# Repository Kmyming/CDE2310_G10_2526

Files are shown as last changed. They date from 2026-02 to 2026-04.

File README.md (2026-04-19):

# Fundamentals of System Design – CDE2310

> A ROS2-based autonomous mission stack using LiDAR, RPi Camera & Rack-and-Pinion Spring-Loaded Launcher for a warehouse maze environment deployment.

## 📘 Project Overview

Welcome to the official repository for our CDE2310 System Design project — a fully autonomous robot capable of:

- 🌐 Frontier exploration, real-time mapping, & FSM Orchestration
- 📷 Detecting static and dynamic delivery zones via ArUco Markers
- 🚀 Dock at delivery zones to launch ping pong ball payloads into delivery receptacles

---
## 📄 Documentation Map

- [Requirements Specification](docs/requirements-specification.md)
- [Concept of Operations](docs/con-ops.md)
- [High Level Design](docs/high-level-design.md)
- [Software Subsystem: Navigation and FSM](docs/subsystem-nav-fsm.md)
- [Software Subsystem: ArUco Marker Detection](docs/subsystem-software-aruco.md)
- [Mechanical Subsystem](docs/subsystem-mechanical.md)
- [Electrical Subsystem](docs/subsystem-electrical.md)
- [Interface Control Document](docs/interface-control-document.md)
- [Software and Firmware Development](docs/software-firmware-development.md)
- [Testing Documentation](docs/testing-documentation.md)
- [User Manual](docs/user-manual.md)
- [Areas for Improvement](docs/improvements.md)
- [Appendix](docs/appendix.md)

👉 **Visit our GitHub Pages site here**:  
🔗 [https://kmyming.github.io/CDE2310_G10_2526/](https://kmyming.github.io/CDE2310_G10_2526/)

## 📂 Project Structure

This repository includes:

- `/docs`: Website content served via GitHub Pages
- `/src`: ROS2 packages and simulation files
- CAD models and system schematics
- Launch and config files for simulation and real-world deployment

---

## 🧥 Meet the Team

<div style="text-align: center;">
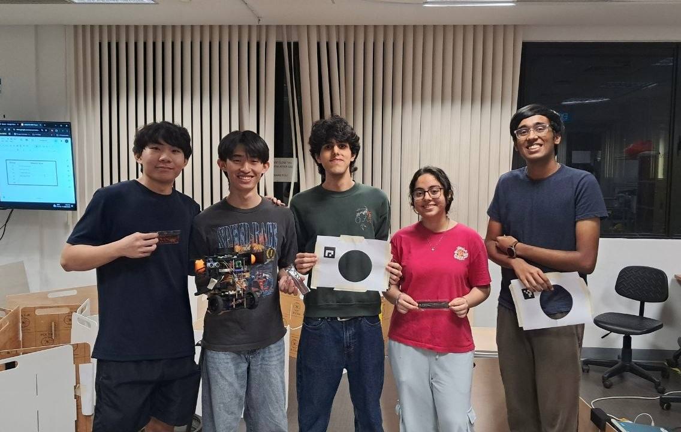
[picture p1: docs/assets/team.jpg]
team
  
</div>

---

## 🛠️ Tech Stack

- ROS2 Humble
- SLAM Toolbox
- Custom Open-source ROS2 Frontier-based exploration
- OpenCV ArUco marker detection
- Python / C++
- Custom 3D-printed parts + electronics integration

---

## Notes
- `CHANGELOG.md` is the repository release-history reference.

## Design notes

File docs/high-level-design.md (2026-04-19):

## 🔗 Navigation

- [Home](index.md)
- [Requirements Specification](requirements-specification.md)
- [Concept of Operations](con-ops.md)
- [High Level Design](high-level-design.md)
- [Software Subsystem: Navigation and FSM](subsystem-nav-fsm.md)
- [Software Subsystem: ArUco Marker Detection](subsystem-software-aruco.md)
- [Mechanical Subsystem](subsystem-mechanical.md)
- [Electrical Subsystem](subsystem-electrical.md)
- [Interface Control Document](interface-control-document.md)
- [Software and Firmware Development](software-firmware-development.md)
- [Testing Documentation](testing-documentation.md)
- [User Manual](user-manual.md)
- [Areas for Improvement](improvements.md)
- [Appendix](appendix.md)

---

# High Level Design

## System Overview

The system is a ROS 2 Humble-based autonomous mobile robot (AMR) built on a TurtleBot3 Burger platform. It is split across two compute nodes: a **remote laptop** running the mission orchestration, SLAM, and navigation stack, and an **on-board Raspberry Pi 4** handling camera processing, docking control, and hardware actuation.

The five core subsystems — Navigation & SLAM, Finite State Machine (FSM), ArUco Marker Detection, Docking Controller, and Shooter Controller — run as independent ROS 2 nodes and communicate exclusively through published topics. No direct function calls cross subsystem boundaries.

---

## Deployment Architecture

The system compute is split between two hosts. The laptop handles all heavy processing; the Pi handles all hardware-facing tasks.

### Remote Laptop (Ubuntu 22.04)

- SLAM Toolbox → Generates `/map` for navigation  
- exploration_controller → Frontier exploration, A* path planning, pure pursuit tracking  
- fsm_controller → Mission state management and velocity multiplexing  
- RViz → Visualisation of map, robot pose, and paths  

### On-board Raspberry Pi 4

- aruco_pose_streamer → ArUco marker detection and TF pose publishing  
- docking_controller → Marker-guided docking control  
- shooter_controller → Launcher actuation and ultrasonic sensing  
- Sensors → Camera and LiDAR inputs  

### Communication

- All nodes communicate using ROS 2 DDS over Wi-Fi  
- No direct function calls between subsystems  
- All data exchange occurs via ROS 2 topics  

---

| Layer | Host | Responsibilities |
|---|---|---|
| **Laptop** | Remote PC (Ubuntu 22.04) | SLAM Toolbox, `exploration_controller`, `fsm_controller`, RViz visualisation |
| **Robot** | Raspberry Pi 4 (on-board) | `aruco_pose_streamer`, `docking_controller`, `shooter_controller`, camera + LiDAR |
---

## Runtime Components

| Node | Host | Role |
|---|---|---|
| `exploration_controller` | Laptop | Frontier-based exploration, A\* path planning, pure-pursuit tracking |
| `fsm_controller` | Laptop | Top-level mission state machine and velocity multiplexer |
| `aruco_pose_streamer` | Pi | ArUco marker detection and TF pose broadcast |
| `docking_controller` | Pi | Multi-stage marker-guided docking state machine |
| `shooter_controller` | Pi | Rack-and-pinion ball delivery, ultrasonic sensing, GPIO actuation |
| SLAM Toolbox | Laptop | Real-time 2D occupancy grid construction and localisation |
| RViz | Laptop | Live map, robot pose, and path visualisation |

---

## ROS 2 Data Flow

The diagram below shows how sensor data flows through all nodes to the motors, and how status signals feed back to the FSM.

```mermaid
flowchart TD
    LIDAR["/scan<br>LiDAR"] --> SLAM
    LIDAR --> EXP
    LIDAR --> DOCK

    ODOM["/odom<br>Odometry"] --> SLAM
    ODOM --> EXP
    ODOM --> DOCK

    CAM["/camera/image_raw<br>Camera"] --> ARUCO

    SLAM["SLAM Toolbox"] -->|/map| EXP

    ARUCO["aruco_pose_streamer"] -->|/tf aruco_marker_id| DOCK
    ARUCO -->|/marker_detected| FSM

    EXP["exploration_controller"] -->|/cmd_vel_nav| FSM
    EXP -->|/map_explored| FSM

    FSM["fsm_controller"] -->|/states| DOCK
    FSM -->|/shoot_type| SHOOT
    FSM -->|/cmd_vel| MOTORS

    DOCK["docking_controller"] -->|/cmd_vel_docking| FSM
    DOCK -->|/dock_done| FSM

    SHOOT["shooter_controller"] -->|/shoot_done| FSM

    MOTORS["TurtleBot3 Motors"]
```

---

## Mission State Flow

```mermaid
flowchart TD
    START(["Mission start"]) --> EXPLORE

    EXPLORE["EXPLORE<br>Frontier navigation"] -->|marker detected<br>unvisited zone| DOCK

    DOCK["DOCK<br>ArUco approach"] -->|dock_done = True| LAUNCH
    DOCK -->|dock_done = False| EXPLORE

    LAUNCH["LAUNCH<br>Ball delivery"] -->|shoot_done = True<br>+ 15 s hold| BACKUP

    BACKUP["BACKUP<br>Reverse 2 s"] --> EXPLORE

    EXPLORE -->|map_explored = True<br>AND marker_count ≥ 2| END

    END(["END<br>Robot halts"])
```

---

## Subsystem Descriptions

### Navigation & SLAM

The `exploration_controller` node implements autonomous frontier-based exploration. On each planning cycle it:

1. Receives the occupancy grid from `/map` and inflates walls by `expansion_size` cells to create a costmap.
2. Identifies frontier cells — free cells (`0`) adjacent to unknown cells (`-1`) — using a breadth-first scan.
3. Groups contiguous frontier cells using DFS and selects the top 5 largest groups.
4. Scores each group by `frontier_size / path_distance` and selects the highest-scoring reachable group.
5. Plans an A\* path from the robot's current grid cell to the frontier centroid, then fits a B-spline for smooth traversal.
6. Tracks the path using a pure-pursuit controller with a configurable lookahead distance.
7. Layers local obstacle avoidance on top: LiDAR scan sectors detect obstacles within `robot_r` and override path-following with evasive velocity commands.

When no frontier groups remain, `/map_explored = True` is published and exploration halts.

### Finite State Machine (FSM)

The `fsm_controller` node is the mission arbiter. It maintains the top-level state and acts as a **velocity multiplexer**, forwarding the correct controller's `Twist` output to `/cmd_vel` depending on the active state.

**Velocity multiplexing:**

| FSM State | Source published to `/cmd_vel` |
|---|---|
| `EXPLORE` | `/cmd_vel_nav` (exploration controller) |
| `DOCK` | `/cmd_vel_docking` (docking controller) |
| `BACKUP` | Hard-coded reverse: `linear.x = -0.1 m/s` |
| `LAUNCH`, `END` | Zero velocity (`Twist()`) |

### ArUco Marker Detection

The `aruco_pose_streamer` node runs on the Pi and processes every camera frame:

1. Converts ROS 2 `Image` messages to OpenCV `BGR` frames via `cv_bridge`.
2. Detects ArUco markers using `DICT_4X4_250` and `DetectorParameters`.
3. Estimates 6-DOF pose using `cv2.aruco.estimatePoseSingleMarkers` with camera intrinsics from `/camera/camera_info` (fallback pinhole model if intrinsics are invalid).
4. Broadcasts each detected marker's pose as a TF transform (`aruco_marker_<id>`).
5. Publishes `/marker_detected = True` (deduplicated — only published on state change).

Zone identification: marker ID `0` → `static` zone, marker ID `1` → `dynamic` zone.

### Docking Controller

The `docking_controller` node executes a geometric perpendicular docking manoeuvre guided by the ArUco marker's `tvec` and `rvec`.

```mermaid
flowchart TD
    IDLE([IDLE]) -->|FSM signals DOCK<br>+ marker visible| SEARCH
    SEARCH["SEARCH<br>Rotate until tx ≈ 0"] --> APPROACH
    APPROACH["APPROACH_1<br>Drive until tz < 0.30 m"] --> TURN_SIDE
    TURN_SIDE["TURN_SIDE<br>Rotate by π/2 − θ"] --> DRIVE_SIDE
    DRIVE_SIDE["DRIVE_SIDE<br>Drive lateral distance"] --> TURN_FACE
    TURN_FACE["TURN_FACE_MARKER<br>Re-centre tx ≈ 0"] --> FINAL
    FINAL["FINAL_APPROACH<br>Drive until tz < 0.10 m"] --> DONE(["DONE<br>/dock_done = True"])

    APPROACH -->|obstacle detected| OBS
    TURN_SIDE -->|obstacle detected| OBS
    DRIVE_SIDE -->|obstacle detected| OBS
    TURN_FACE -->|obstacle detected| OBS

    OBS["OBSTACLE_AVOIDANCE<br>Evade obstacle"] --> SPEC
    SPEC["SPECIAL_SEARCH<br>360° rotation"] -->|marker found| SEARCH
    SPEC -->|no marker| ABORT

    APPROACH -->|timeout| ABORT
    FINAL -->|timeout| ABORT

    ABORT(["ABORT<br>/dock_done = False"]) --> IDLE
    DONE --> IDLE
```

Key geometric logic in `APPROACH_1` → `TURN_SIDE`:

- Computes angle `θ` between the marker normal and the camera→marker vector using the marker's rotation matrix.
- Plans a lateral step of distance `tz × sin(θ)` to reach the perpendicular line.
- Turns by `(π/2 − |θ|)` to face perpendicular, drives the lateral distance, then turns back to face the marker.

**Watchdog timers** (both trigger `ABORT`):
- Marker invisible for > **30 seconds** continuously.
- Any single docking state active for > **45 seconds**.

### Shooter Controller

The `shooter_controller` node manages ball delivery via two servos and one ultrasonic sensor connected to the Pi's GPIO through `pigpio`:

| Component | GPIO Pin | Function |
|---|---|---|
| Gate servo | Pin 12 | Opens/closes to release one ball |
| Rack servo | Pin 13 | Continuous rotation — pulls back the launcher rack |
| Ultrasonic trigger | Pin 23 | HC-SR04 trigger pulse |
| Ultrasonic echo | Pin 24 | HC-SR04 echo return |

```mermaid
flowchart TD
    START([/shoot_type received]) --> TYPE{shoot_type?}

    TYPE -->|static| S1["Shot 1"]
    S1 --> S2["Shot 2"]
    S2 --> S3["Shot 3"]
    S3 --> DONE

    TYPE -->|dynamic| POLL["Poll ultrasonic"]
    POLL -->|distance > threshold| POLL
    POLL -->|distance ≤ threshold| LOAD["Load pass"]
    LOAD --> POLL2["Poll again"]
    POLL2 -->|distance ≤ threshold| LAUNCH["Launch"]
    LAUNCH --> DONE

    DONE(["/shoot_done = True"])
```

Ultrasonic distance is computed as a **median of 5 samples**, filtering out readings outside `[0.02 m, 4.0 m]`. Speed of sound is corrected for ambient temperature (`331.3 + 0.606 × T °C` m/s).

---

## ROS 2 Topic Summary

| Topic | Type | Publisher | Subscriber(s) |
|---|---|---|---|
| `/scan` | `LaserScan` | LiDAR driver | `exploration_controller`, `docking_controller` |
| `/odom` | `Odometry` | TurtleBot3 bringup | `exploration_controller`, `docking_controller` |
| `/map` | `OccupancyGrid` | SLAM Toolbox | `exploration_controller` |
| `/camera/image_raw` | `Image` | Camera node | `aruco_pose_streamer` |
| `/camera/camera_info` | `CameraInfo` | Camera node | `aruco_pose_streamer` |
| `/tf` | `TFMessage` | `aruco_pose_streamer` | `docking_controller`, `fsm_controller` |
| `/marker_detected` | `Bool` | `aruco_pose_streamer` | `fsm_controller` |
| `/cmd_vel_nav` | `Twist` | `exploration_controller` | `fsm_controller` |
| `/cmd_vel_docking` | `Twist` | `docking_controller` | `fsm_controller` |
| `/cmd_vel` | `Twist` | `fsm_controller` | TurtleBot3 motor driver |
| `/states` | `String` | `fsm_controller` | `docking_controller` |
| `/dock_done` | `Bool` | `docking_controller` | `fsm_controller` |
| `/shoot_type` | `String` | `fsm_controller` | `shooter_controller` |
| `/shoot_done` | `Bool` | `shooter_controller` | `fsm_controller` |
| `/map_explored` | `Bool` | `exploration_controller` | `fsm_controller` |
| `/exploration_path` | `Path` | `exploration_controller` | RViz |

---

## Design Rationale

**Decoupled subsystems via topics** — each node publishes and subscribes to well-defined topics. This allows any subsystem to be swapped, tested in isolation, or replaced without modifying other nodes.

**Laptop/Pi compute split** — SLAM and A\* are CPU-intensive; keeping them on the laptop prevents the Pi from becoming a bottleneck during real-time marker detection and GPIO actuation.

**Velocity multiplexer in FSM** — rather than having multiple nodes write directly to `/cmd_vel`, the FSM acts as a single gatekeeper. This prevents conflicting velocity commands and makes the priority logic explicit and auditable.

**Watchdog timers in docking** — the 30-second marker-loss watchdog and 45-second per-state watchdog ensure the robot never stalls indefinitely in a partially completed docking attempt, always returning to a known safe state (`ABORT` → `IDLE`).

**Parameter-driven configuration** — all thresholds, speeds, pin assignments, and timing values are exposed as ROS 2 parameters loaded from `params.yaml` at launch. No magic numbers exist in business logic, making tuning and re-calibration straightforward.

**Simulation parity** — the `enable_hardware = False` flag on the shooter node and standard Gazebo-compatible topic names mean the full software stack can be validated in simulation before any hardware run.

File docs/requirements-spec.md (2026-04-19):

# 🔗 Navigation
- [Home](index.md)
- [Requirements Specification](requirements-specification.md)
- [Concept of Operations](con-ops.md)
- [High Level Design](high-level-design.md)
- [Software Subsystem: Navigation and FSM](subsystem-nav-fsm.md)
- [Software Subsystem: ArUco Marker Detection](subsystem-software-aruco.md)
- [Mechanical Subsystem](subsystem-mechanical.md)
- [Electrical Subsystem](subsystem-electrical.md)
- [Interface Control Document](interface-control-document.md)
- [Software and Firmware Development](software-firmware-development.md)
- [Testing Documentation](testing-documentation.md)
- [User Manual](user-manual.md)
- [Areas for Improvement](improvements.md)
- [Appendix](appendix.md)

---

# Requirements Specification

## Problem Statement

The system must autonomously explore an unknown indoor warehouse-style arena, detect ArUco fiducial markers identifying two delivery receptacles, dock precisely in front of each receptacle, and deliver exactly three ping-pong balls per receptacle — all without manual teleoperation after mission start. One receptacle is static; the other moves laterally at an unknown speed, requiring sensor-gated delivery timing. The complete mission must be executed within a **25-minute window** on a TurtleBot3 Burger platform running ROS 2 Humble.

---

## Stakeholder Needs

- Autonomous exploration of a fully unknown maze environment with no prior map.
- Reliable detection and 6-DOF pose estimation of ArUco markers under realistic lighting and partial occlusion.
- Deterministic mission state transitions that handle both success and failure paths without operator input.
- Correct, sequenced ball delivery into both a static and a moving receptacle.
- Clear operator setup and shutdown procedures requiring minimal technical expertise.
- A single-command launch that brings up the full mission stack for both simulation and real hardware.

---

## Functional Requirements

### Navigation and Mapping

**FR-01** — The system shall autonomously build a 2D occupancy grid of the arena using LiDAR-based SLAM without any prior map data.

**FR-02** — The system shall implement frontier-based exploration to discover and navigate to unexplored regions of the map systematically, scoring frontiers by a ratio of frontier size to A\* path distance.

**FR-03** — The system shall plan collision-free paths to frontier targets using the A\* algorithm on the inflated costmap and track those paths using a pure-pursuit controller.

**FR-04** — The system shall apply local obstacle avoidance using segmented LiDAR scan sectors, overriding path-following commands when obstacles are detected within `robot_r` of the robot body.

**FR-05** — The system shall publish a `/map_explored` signal (`Bool`, `True`) when no valid frontier groups remain in the occupancy grid.

### Marker Detection

**FR-06** — The system shall detect ArUco markers (dictionary `DICT_4X4_250`) from the Raspberry Pi camera feed and estimate their 6-DOF pose (translation vector `tvec`, rotation vector `rvec`) using OpenCV's `estimatePoseSingleMarkers`.

**FR-07** — The system shall broadcast each detected marker's pose as a TF transform (`aruco_marker_<id>`) and publish a `/marker_detected` (`Bool`) signal when at least one marker is visible.

**FR-08** — The system shall identify the delivery zone type from the marker ID: marker ID `0` corresponds to the static receptacle zone; marker ID `1` corresponds to the dynamic receptacle zone.

**FR-09** — The system shall use a fallback pinhole camera model when valid intrinsics are not available from `/camera/camera_info`, logging a warning and continuing detection.

**FR-10** — The system shall suppress duplicate zone-detection signals: once a zone has been marked as visited by the FSM, further detections of that zone's marker shall be ignored.

### Mission State Machine

**FR-11** — The system shall implement a finite state machine (FSM) with the following top-level states: `EXPLORE`, `DOCK`, `LAUNCH`, `BACKUP`, and `END`.

**FR-12** — The FSM shall transition from `EXPLORE` to `DOCK` upon receiving a `/marker_detected = True` signal for an unvisited zone while in the `EXPLORE` state.

**FR-13** — The FSM shall transition from `DOCK` to `LAUNCH` upon receiving `/dock_done = True`, and return to `EXPLORE` upon receiving `/dock_done = False`.

**FR-14** — The FSM shall transition from `LAUNCH` to `BACKUP` after the shooter signals `/shoot_done = True` and a minimum hold duration of 15 seconds has elapsed.

**FR-15** — The FSM shall transition from `BACKUP` to `EXPLORE` after the robot has reversed for 2 seconds, clearing the delivery zone.

**FR-16** — The FSM shall transition to `END` when the map is fully explored and both delivery zones have been visited (`marker_count >= 2`).

**FR-17** — The FSM shall arbitrate velocity commands from the navigation controller (`/cmd_vel_nav`) and the docking controller (`/cmd_vel_docking`), publishing the active controller's output to `/cmd_vel` based on the current state.

### Docking

**FR-18** — The docking controller shall implement a multi-stage docking state machine with the states: `IDLE`, `SEARCH`, `APPROACH_1`, `TURN_SIDE`, `DRIVE_SIDE`, `TURN_FACE_MARKER`, `FINAL_APPROACH`, `DONE`, `ABORT`, `OBSTACLE_AVOIDANCE`, and `SPECIAL_SEARCH`.

**FR-19** — The docking controller shall rotate the robot until the marker's lateral offset `tx` is within ±0.01 m before beginning the approach.

**FR-20** — The docking controller shall compute a geometric perpendicular approach manoeuvre using the marker's pose angle `θ` when `tz < 0.30 m`, including a lateral drive step and a realignment turn.

**FR-21** — The docking controller shall terminate the final approach and publish `/dock_done = True` when `tz < 0.10 m` or the front LiDAR average reads below `0.20 m`.

**FR-22** — The docking controller shall publish `/dock_done = False` and transition to `ABORT` if the marker is continuously invisible for 30 seconds during any active docking state, or if any single docking state remains active for more than 45 seconds.

**FR-23** — The docking controller shall transition to `OBSTACLE_AVOIDANCE` when a proximate obstacle is detected during any docking state (except `FINAL_APPROACH`, `SPECIAL_SEARCH`, `DONE`, `ABORT`, and `IDLE`), and subsequently perform a 360° rotation scan (`SPECIAL_SEARCH`) to re-acquire the marker.

### Payload Delivery

**FR-24** — The shooter controller shall deliver exactly three ping-pong balls per docking event, using a rack-and-pinion servo mechanism actuated via GPIO through `pigpio`.

**FR-25** — For the static receptacle (`shoot_type = static`), the shooter shall fire three shots with the following inter-shot delays: ~0.1 s between shots 1 and 2, and ~7.1 s between shots 2 and 3.

**FR-26** — For the dynamic receptacle (`shoot_type = dynamic`), the shooter shall poll an ultrasonic sensor (HC-SR04 or equivalent) at regular intervals and only trigger each shot when the measured distance to the moving receptacle is ≤ 0.70 m, using a two-pass load-then-launch sequence.

**FR-27** — The shooter shall use a median of multiple ultrasonic samples per measurement to reduce noise, filtering out readings outside the valid range of `0.02 m` to `4.0 m`.

**FR-28** — The shooter controller shall publish `/shoot_done = True` upon successful completion of the full delivery sequence and `/shoot_done = False` on any exception during hardware actuation.

**FR-29** — The shooter controller shall support an `enable_hardware = False` simulation mode that completes the delivery sequence after a configurable delay without actuating any GPIO pins.

---

## Non-Functional Requirements

**NFR-01** — The entire mission stack shall be launchable with a single top-level `ros2 launch` command for both the simulation and real-hardware configurations.

**NFR-02** — The system shall expose stable, documented ROS 2 topic contracts (topic names, message types, QoS profiles) so that each subsystem can be developed, tested, and replaced independently.

**NFR-03** — All tunable parameters (speeds, thresholds, timeouts, pin assignments, servo pulse widths) shall be exposed as ROS 2 parameters configurable at launch time via a `params.yaml` file, with no hardcoded values in business logic.

**NFR-04** — The documentation shall be written in Markdown and remain compatible with GitHub Pages rendering.

**NFR-05** — The system shall log all state transitions and key sensor readings to `/rosout` at the `INFO` level to support post-run debugging.

---

## Constraints

**CON-01** — The robot platform is a TurtleBot3 Burger. No modifications to the core drive train or LiDAR mounting are permitted.

**CON-02** — The software stack shall target ROS 2 Humble on Ubuntu 22.04.

**CON-03** — Line-following techniques are prohibited. Navigation must be SLAM and sensor-based.

**CON-04** — The robot shall operate fully autonomously from the moment the mission clock starts. No teleoperation is permitted during the mission.

**CON-05** — The mission must be completed within 25 minutes.

**CON-06** — No more than six ArUco landmark markers may be used across the entire arena.

**CON-07** — The LiDAR's 360° field of view must not be obstructed by any mechanical or storage component mounted on the robot.

**CON-08** — The compute responsibilities are split: the Raspberry Pi 4 (on-board) handles camera processing, docking, and hardware actuation; the remote laptop handles SLAM, navigation, and the FSM.

---

## Performance Requirements

**PR-01** — The robot shall align with delivery receptacles with a lateral positional error of no more than ±10 cm at the point of delivery.

**PR-02** — The ball dispensing success rate (ball lands and remains inside the receptacle) shall be at least 70% per shot under normal operating conditions.

**PR-03** — The exploration algorithm shall cover at least 80% of the accessible arena area before declaring the map fully explored.

**PR-04** — The ArUco marker detection pipeline shall process camera frames in real time (≥10 Hz) and publish pose data with a latency of no more than 200 ms from frame capture.

**PR-05** — The docking controller shall complete a full docking sequence (from `SEARCH` to `DONE`) within 45 seconds per docking attempt under normal visibility conditions.

---

## Interface Requirements

**IR-01** — The operator shall be able to start the full mission stack by typing a single `ros2 launch` command on the remote laptop and a single bringup command on the Raspberry Pi.

**IR-02** — An RViz instance shall be available on the remote laptop during the mission, displaying the live occupancy grid, robot pose, and planned path.

**IR-03** — All inter-subsystem communication shall use standard ROS 2 message types (`Twist`, `Bool`, `String`, `LaserScan`, `OccupancyGrid`, `Odometry`, `TFMessage`, `Image`, `CameraInfo`). No custom message types are used.

---

## Operating Environment

**OE-01** — The arena is an indoor, flat-floored warehouse-style maze with walls tall enough to be detected by the TurtleBot3's LiDAR (minimum wall height: 20 cm).

**OE-02** — ArUco markers are placed in well-lit positions. The camera must be able to detect markers from at least 1.5 m distance under ambient indoor lighting.

**OE-03** — The dynamic receptacle moves laterally within a fixed range. The ultrasonic sensor mounted on the robot must have a clear line of sight to the receptacle during the delivery phase.

---

## Safety Requirements

**SR-01** — The system shall stop all motor output (publish zero-velocity `Twist`) whenever transitioning to the `DONE`, `ABORT`, or `END` states.

**SR-02** — The `destroy_node()` method of each controller node shall publish a zero-velocity `Twist` before shutting down, preventing runaway motion on node death.

**SR-03** — The shooter hardware (servos, GPIO) shall be safely de-energised in the `ShooterController.destroy_node()` method, setting all servo pulse widths to 0 and releasing the `pigpio` connection.

**SR-04** — The system may be interrupted at any time with `Ctrl+C`. All nodes shall handle `KeyboardInterrupt` gracefully and execute their shutdown procedures.

**SR-05** — Physical intervention (catching or stopping the robot) by the operator is permitted if the robot is observed to be causing damage to the arena or to itself.

---

## Acceptance Criteria

| ID | Criterion | Pass Condition |
|---|---|---|
| AC-01 | Single-command launch | Full stack starts without errors from one `ros2 launch` command |
| AC-02 | Map construction | A populated occupancy grid is visible in RViz within 30 s of launch |
| AC-03 | Frontier exploration | Robot visits at least 80% of accessible arena area before `/map_explored = True` |
| AC-04 | Marker detection | `/marker_detected = True` published within 3 s of a marker entering the camera frame |
| AC-05 | Zone discrimination | FSM correctly identifies `static` vs `dynamic` zone from marker ID in all test runs |
| AC-06 | Successful docking | Robot stops within ±10 cm laterally of the receptacle centre in ≥ 80% of docking attempts |
| AC-07 | Static delivery | All 3 balls delivered into the static receptacle without the shooter faulting |
| AC-08 | Dynamic delivery | At least 2 of 3 balls delivered into the moving receptacle across a full mission run |
| AC-09 | Fault recovery | FSM returns to `EXPLORE` within 5 s of a docking `ABORT` signal |
| AC-10 | Safe shutdown | Robot stops completely within 1 s of `Ctrl+C`; no GPIO pins remain energised |

---

## Requirement Traceability

| Requirement | Primary Doc | Validation Doc |
|---|---|---|
| FR-01, FR-02, FR-03, FR-04, FR-05 | [Software Subsystem: Navigation and FSM](subsystem-nav-fsm.md) | [Testing Documentation](testing-documentation.md) |
| FR-06, FR-07, FR-08, FR-09, FR-10 | [Software Subsystem: ArUco Marker Detection](subsystem-software-aruco.md) | [Testing Documentation](testing-documentation.md) |
| FR-11 – FR-17 | [Software Subsystem: Navigation and FSM](subsystem-nav-fsm.md) | [Interface Control Document](interface-control-document.md) |
| FR-18 – FR-23 | [High Level Design](high-level-design.md) | [Testing Documentation](testing-documentation.md) |
| FR-24 – FR-29 | [Electrical Subsystem](subsystem-electrical.md) | [Testing Documentation](testing-documentation.md) |
| NFR-01, NFR-02, NFR-03 | [Software and Firmware Development](software-firmware-development.md) | [User Manual](user-manual.md) |
| NFR-04 | [Home](index.md) | — |
| NFR-05 | [Software and Firmware Development](software-firmware-development.md) | [Testing Documentation](testing-documentation.md) |
| CON-01 – CON-08 | [High Level Design](high-level-design.md) | — |
| PR-01 – PR-05 | [High Level Design](high-level-design.md) | [Testing Documentation](testing-documentation.md) |
| IR-01 – IR-03 | [Interface Control Document](interface-control-document.md) | [User Manual](user-manual.md) |
| SR-01 – SR-05 | [Software and Firmware Development](software-firmware-development.md) | [Testing Documentation](testing-documentation.md) |

---

## Open Assumptions

- The operator launches the system from the documented workspace with the correct ROS 2 environment sourced.
- Camera and LiDAR topics are available and publishing at the expected rates in the selected runtime mode before the mission clock starts.
- The arena walls and obstacles are detectable by the TurtleBot3's LiDAR at all points in the maze.
- The dynamic receptacle's period of motion is slow enough for the ultrasonic-gated delivery approach to achieve at least one valid shot window per polling cycle.

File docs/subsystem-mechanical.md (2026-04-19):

## 🔗 Navigation

- [Home](index.md)
- [Requirements Specification](requirements-specification.md)
- [Concept of Operations](con-ops.md)
- [High Level Design](high-level-design.md)
- [Software Subsystem: Navigation and FSM](subsystem-nav-fsm.md)
- [Software Subsystem: ArUco Marker Detection](subsystem-software-aruco.md)
- [Mechanical Subsystem](subsystem-mechanical.md)
- [Electrical Subsystem](subsystem-electrical.md)
- [Interface Control Document](interface-control-document.md)
- [Software and Firmware Development](software-firmware-development.md)
- [Testing Documentation](testing-documentation.md)
- [User Manual](user-manual.md)
- [Areas for Improvement](improvements.md)
- [Appendix](appendix.md)

---

# Mechanical Subsystem
<div style="text-align: center;">
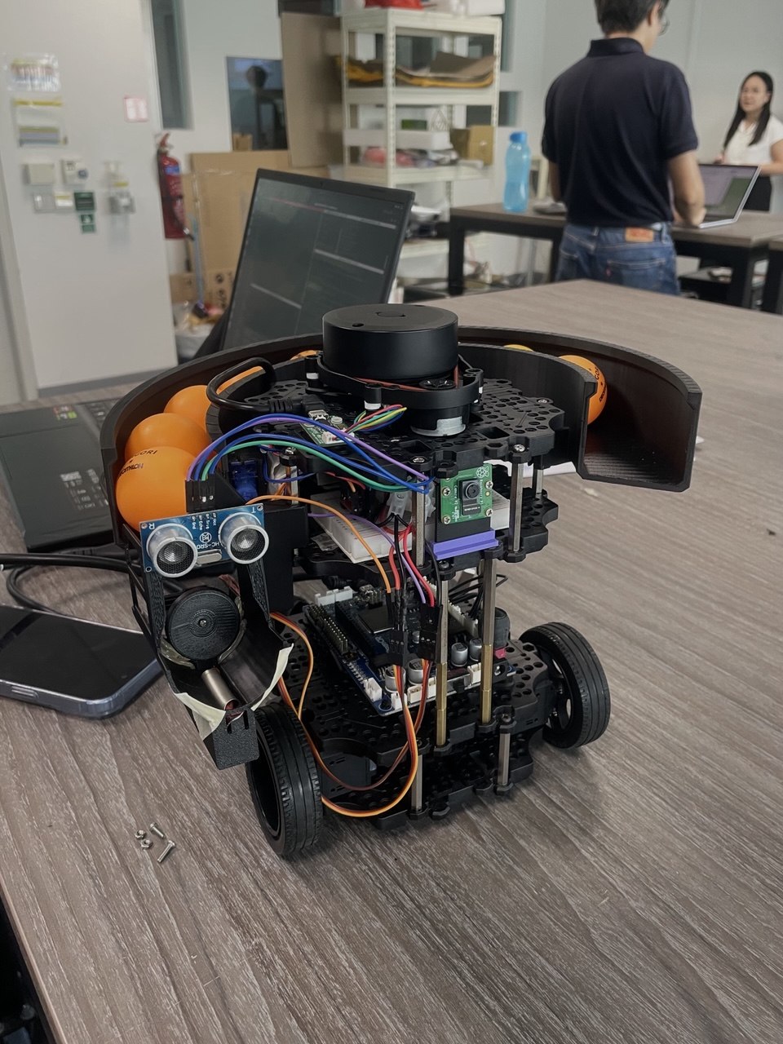
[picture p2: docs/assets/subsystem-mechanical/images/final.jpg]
final
  
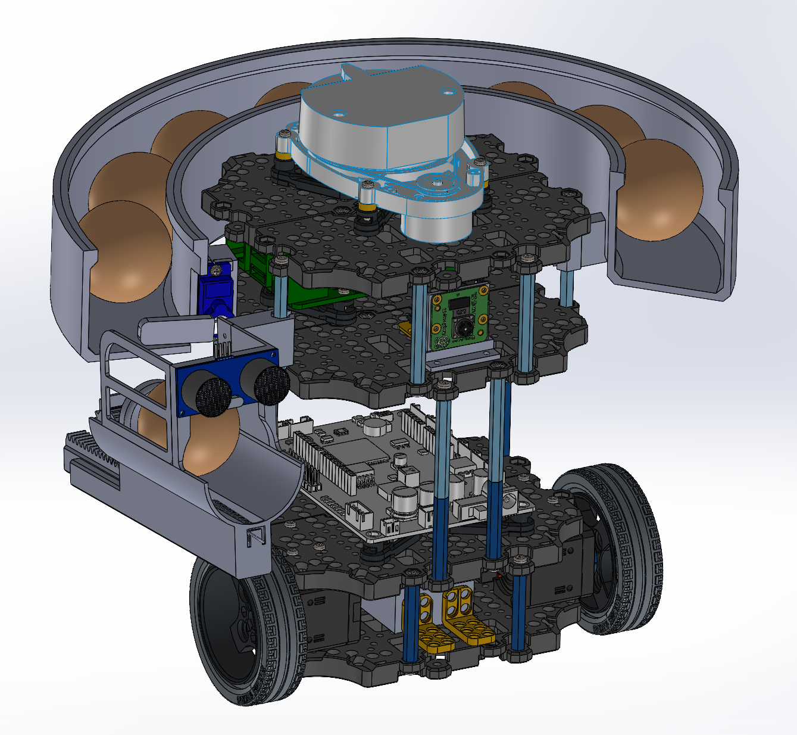
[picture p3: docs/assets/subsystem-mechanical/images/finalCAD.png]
finalCAD
   
</div>

## Problem Description

The mechanical subsystem needs to aid in the successful delivery of 3 ping pong balls per delivery receptacle once the turtlebot is docked. There are 2 delivery zones - static & dynamic. The delivery sequence is per a specific timing sequence at the static delivery zone, with no timing sequence at the dynamic delivery zone, but must be able to successfully deliver 3 ping pong balls into a moving delivery receptacle. It must be designed to store and launch ping pong balls reliably from a TurtleBot3 platform without compromising stability, safety, or sensor visibility. The core challenge is integrating a compact launcher and feed mechanism into limited robot space while maintaining consistent launch performance per the requirements of each delivery zone.

Primary mechanical pain points identified during development were:

- high precision of feeder & rack-and-pinion motion required with low geometric tolerance
- friction losses in the launcher channel
- feed consistency into the launch path & launch consistency
- gear slipping during repeated test cycles

## Design Requirements

### Overall requirements:
- Allow practical assembly and maintenance access for wiring and servo hardware.
- Maintain center-of-gravity placement that does not destabilize the TurtleBot3.
- Keep LiDAR and critical sensing lines of sight unobstructed.

### Storage:
- Hold and guide ping pong balls through a repeatable feed and launch sequence.
- The robot must be able to carry and securely store **nine ping pong balls.**
- Balls must not escape during the mission.
- Feeder should only allow one ball to be fed into the launcher in every feed and launch sequence.

### Launcher:
- Must be able to launch the ping pong ball horizontally forward into delivery receptacles **with a docking distance of 10cm from the camera to the ArUco Marker**.
- Must be able to launch at specific timing intervals at the static delivery zone **(LAUNCH - 1s - LAUNCH - 9s - LAUNCH)**.
- Must be able to launch into a moving delivery receptacle at the dynamic delivery zone with **no prior knowledge of receptacle linear velocity**
- Support rapid iteration and replacement of launcher subassemblies.

### Sensor mounts:
- RPi Camera and Ultrasonic sensor needs to be mounted at the correct angles for proper calibration of markers/correct measurement of distance to detect moving delivery receptacles
- Mounts must be rigid and not allow movement of sensors during operation that can affect sensor data reliability

## System Overview & Machine Elements

The mechanical architecture uses a **servo-driven rack-and-pinion launcher in a tilted launcher assembly** to launch the balls into static and dynamic delivery receptacles. The balls are stored in a **helix storage**, and feeding is controlled via a **servo gate**. The launcher interface is mounted to the robot using **detachable hex-mount geometry** for easier iteration and replacement.

### Key machine elements:
#### 1. Rack-and-Pinion Servo-driven launcher
- 3D-printed: 1x launcher main body, 1x rack, 1x pinion sector gear, 1x conical pusher, 1x servo bracket, 2x hex mounts
- fasteners: 2x M2.5x10 self-tapping screws, 1x M2x15 screw, 1x M2 Nut, 2x M2x15 self-tapping screws, M2.5x5 screw + modified single arm servo horn 
- electronics: 1x MG90S Continuous Rotation Servo Motor, 1x HC-SR04 Ultrasonic Sensor
- Tensioned via 1x Spring and 1x Rubber band

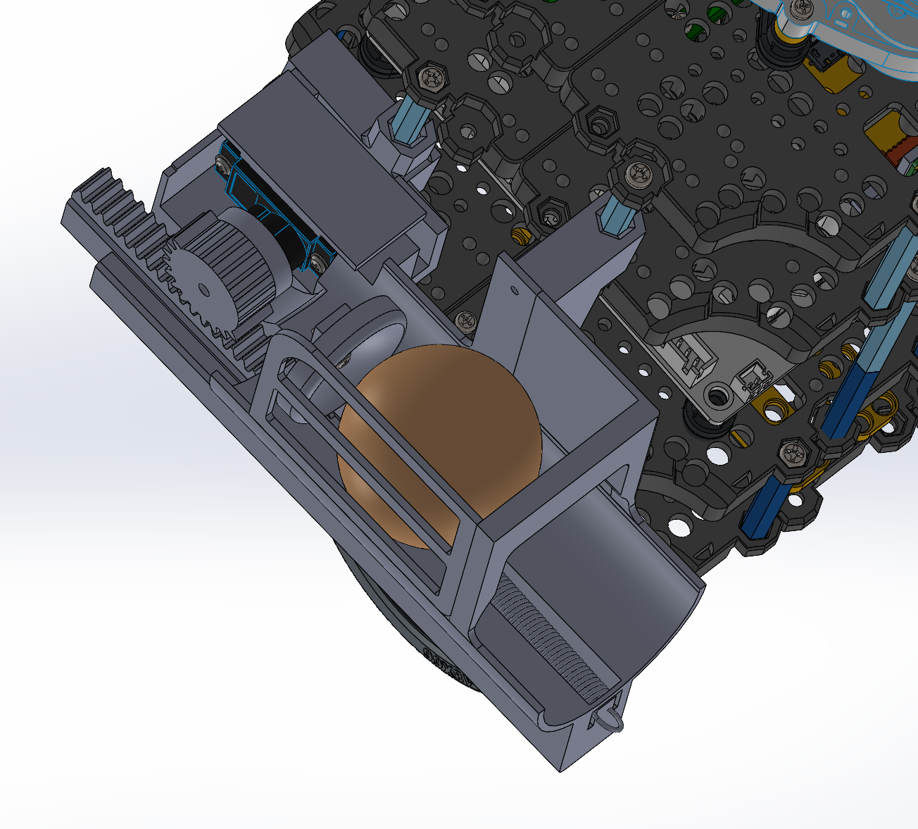
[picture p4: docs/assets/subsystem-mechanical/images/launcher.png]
launcher


#### 2. Helix storage & Servo gate
- 3D-printed: 1x helix storage, 1x servo horn mount
- fasteners: 2x M2.5x10 self-tapping screws, M2.5x5 screw + single arm servo horn 
- electronics: 1x SG90 Servo Motor

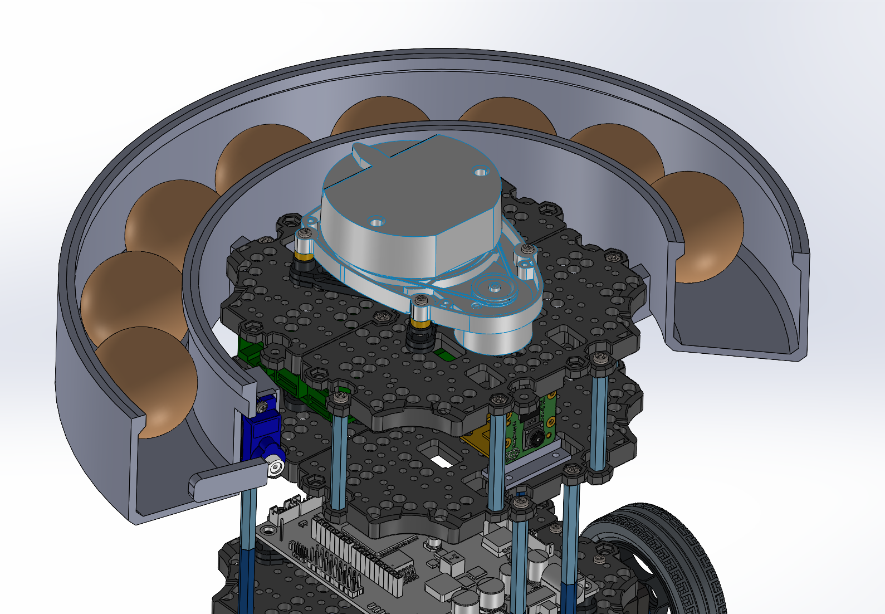
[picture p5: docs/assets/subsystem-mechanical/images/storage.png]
storage


#### 3. RPi Camera:
- 3D-printed: RPi Camera Mount & Stand
- fasteners: 6x M2x15 screws, 6x M2 Nuts
- electronics: RPi Camera V2.1

<div style="text-align: center;">
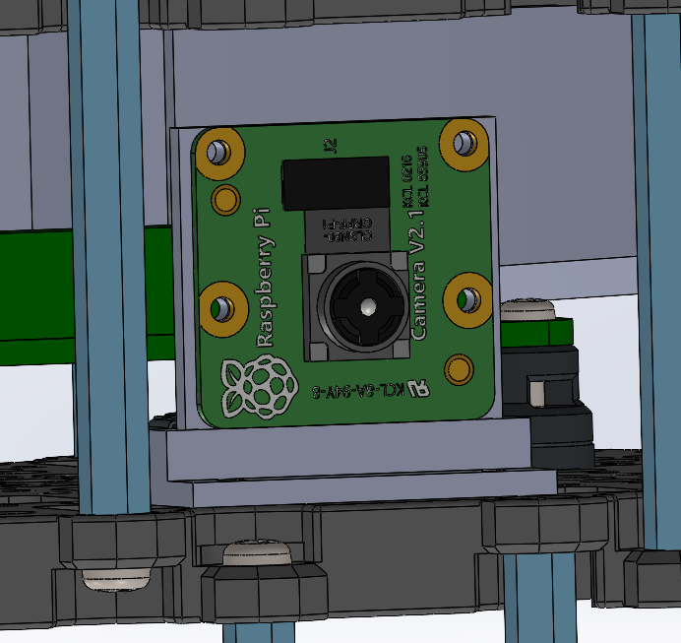
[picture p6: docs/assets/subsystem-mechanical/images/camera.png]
RPi Camera
  
</div>

## Other Strategies

During concept exploration, alternative strategies considered included:

### Storage & feeding:

Vertical stack:

Lets gravity pull the balls down into the launching mechanism. However, this will obstruct the Lidar (Fig. 1). This is easily fixed by stacking the balls in a curved tube (Fig. 2) instead of vertically on top of each other.

<div style="text-align: center;">
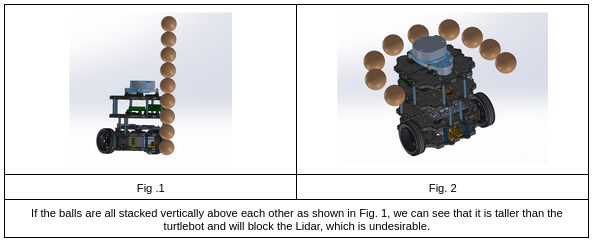
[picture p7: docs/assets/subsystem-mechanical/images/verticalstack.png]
vertical stack
  
</div>

Helix Storage:

The balls can be stored by lining them up one-by-one in a helix structure around the Turtlebot 3, and gravity can pull the balls down to the release zone sequentially. The structure can follow a half-open tube design. A servo gate may be deployed to control the flow of the balls and the number released. 

Ferris Wheel Storage:

Similar to Ferris wheels, the balls can be stored vertically in a circular pattern. The balls will be stored in containers in the wheel. Spinning the wheel will cause one ball to exit the wheel through an opening at the top of the wheel (like a revolver-style release mechanism) into a ramp that slides the ball down to the release zone that can be controlled by a servo gate mechanism. If the wheel is unable to keep all 9 balls, remaining balls can be lined up on the ramp for storage and fed via a servo gate mechanism into the launcher. 

<div style="text-align: center;">
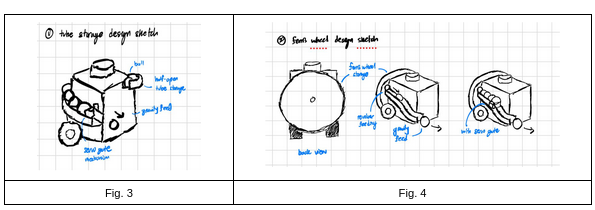
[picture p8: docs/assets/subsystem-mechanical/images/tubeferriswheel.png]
tube & ferris wheel storage
  
</div>

### Launching Mechanism:

Gravity Feed:

This is the lowest energy design utilising no extra motors or actuators. It uses gravity for the ball to gain sufficient kinetic energy to roll into the delivery receptacle. The ball will utilise the half-open tube/ramp to roll down into the delivery receptacle. This design can be paired with both storage & feeding mechanisms. 

Spring-loaded launcher:

This design involves using a spring to push the ball from the release zone into the delivery receptacle. The spring will be initially compressed, using servos as a catch, and when the ball is at the release zone, it is released to launch the ball horizontally into the receptacle. This design can be paired with both storage mechanisms, but will require the servo gate mechanism to set the ball at the release zone unless a coordinated feeding & launching timing sequence is developed. 

<div style="text-align: center;">
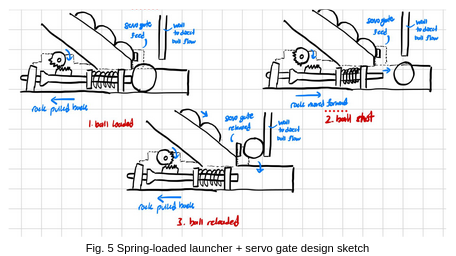
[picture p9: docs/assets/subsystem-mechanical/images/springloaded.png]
spring loaded launching mechanism
  
</div>

Solenoid Plunger:

This design involves using a solenoid plunger system as a pusher to push the ball horizontally forward. When the ball is at the release zone, the plunger is moved forward, launching the ball horizontally into the receptacle. The plunger will then be reset to let the subsequent ball enter the release point for launching. This design can also be paired with both storage mechanisms, but will require the servo gate mechanism to set the ball at the release zone unless a coordinated feeding & launching timing sequence is developed. 

<div style="text-align: center;">
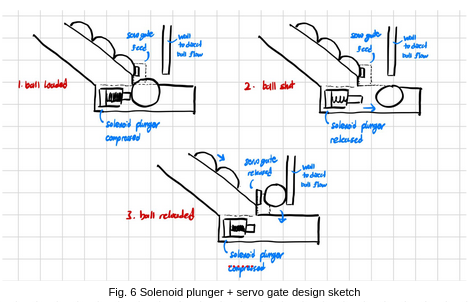
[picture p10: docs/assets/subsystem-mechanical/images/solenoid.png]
solenoid plunger launching mechanism
  
</div>

Flywheel Launcher:

The design would include a wheel that is spinning at >2000 rpm, usually achieved by using one big gear to drive a smaller gear. If not found online, our gears will likely be 3D printed. Depending on what gears we use, we would require the driving motor to spin at different speeds. There are two different flywheel designs: single and double. When the ball is at the release zone, a servo-powered linear actuator will be used to push the ball into the flywheels. The flywheels will come into contact with the ball and launch it horizontally into the receptacle. This design can be paired with both storage & feeding mechanisms. 

<div style="text-align: center;">
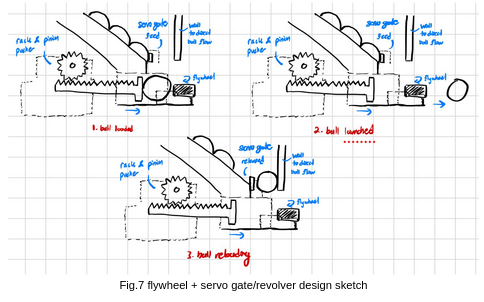
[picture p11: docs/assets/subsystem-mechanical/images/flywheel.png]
flyhweel launching mechanism
  
</div>

## Evaluation of Design Options

| Subsystem | Option | Advantages | Limitations | Other Notes |
|---|---|---|---|---|
| Storage | Tubed storage & feeding | Easy to implement with no additional moving parts. | Less space efficient as balls surround the entire turtlebot, and a large, half-open helix tube structure is required for storage. | If combined with the gravity feed launching mechanism, balls may not gain enough kinetic energy to be launched into the receptacle.|
| Storage | Ferris Wheel storage & feeding | Space-efficient. Balls are kept compact vertically at the back of the turtlebot, with reduced tube required (only for launching mechanism) | Many moving parts, more complicated to implement. Requires an additional motor to control the rotation, which requires additional power. | If servo is not precise enough, the balls may not be released as the holes do not align, or multiple balls may be released at the same time. May obstruct the launching mechanism, and it will protrude out from the back of the turtlebot.|
| Launch | Gravity feed | Easy to implement, as no additional electrical components are required to launch the balls. | As the ball needs to gain sufficient kinetic energy to be able to be launched into the receptacle successfully, the release height of the ball needs to be high enough. | The height of release for the ping pong ball is calculated to be 14.3 cm for a docking tolerance of 15 cm (see Appendix B). This height is too high for both storage mechanisms to be feasibly implemented without blocking the LiDAR (height of turtlebot without LiDAR is 15.2cm).  |
| Launch | Spring-loaded launcher | Simple structure that is relatively easy to implement. | An additional mechanism is required to lengthen the spring. | Failure of the mechanism due to wear and tear. |
| Launch | Solenoid Plunger | Simple structure that is relatively easy to implement. | Additional weight & power requirements make it more complicated to implement. | |
| Launch | Flywheel launcher| Steady, reliable launching power. | Launching power may be too strong for this mission, and the balls may bounce out of the receptacle. More complicated to implement with more moving parts & additional weight & power requirements. | Might squish the ping pong ball too hard and deform it|

For this project context, the tubed storage with servo gate and the rack-and-pinion spring loaded launcher was selected. Tubed storage will not require additional moving parts & will not obstruct the launcher, unlike the Ferris wheel. The spring-loaded launcher has the least additional weight & power requirements with a structure relatively easy to implement, while remaining feasible.

## Assembly Plan

1. 3D Print and post-process primary parts (launcher body, rack, mounts, covers). Procure remaining machine elements required.
2. Verify dimensional fit for rack-pinion sliding and servo interface before full build.
3. Modify MG90S single arm servo horn, removing the arm. Secure into MG90S Servo using 1x M2.5x5. Fit it into pinion gear and secure using super glue.

<div style="text-align: center;">
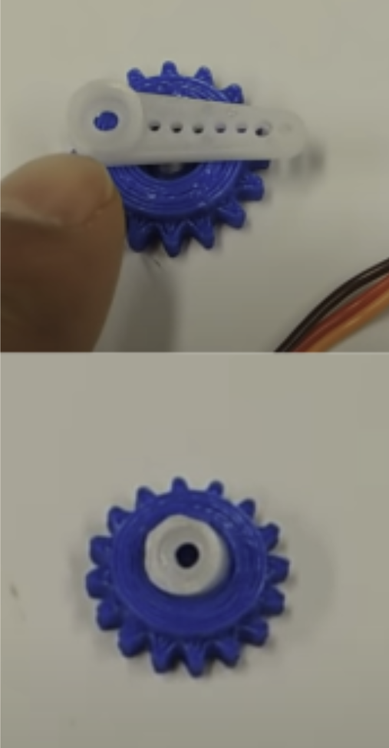
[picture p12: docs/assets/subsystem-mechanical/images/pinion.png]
pinion
  
</div>

3. Assemble Rack with conical pusher using M2x15 and M2 Nut. 
4. Assemble launcher main body with rack and pusher and 1x spring and 1x rubber band.

<div style="text-align: center;">
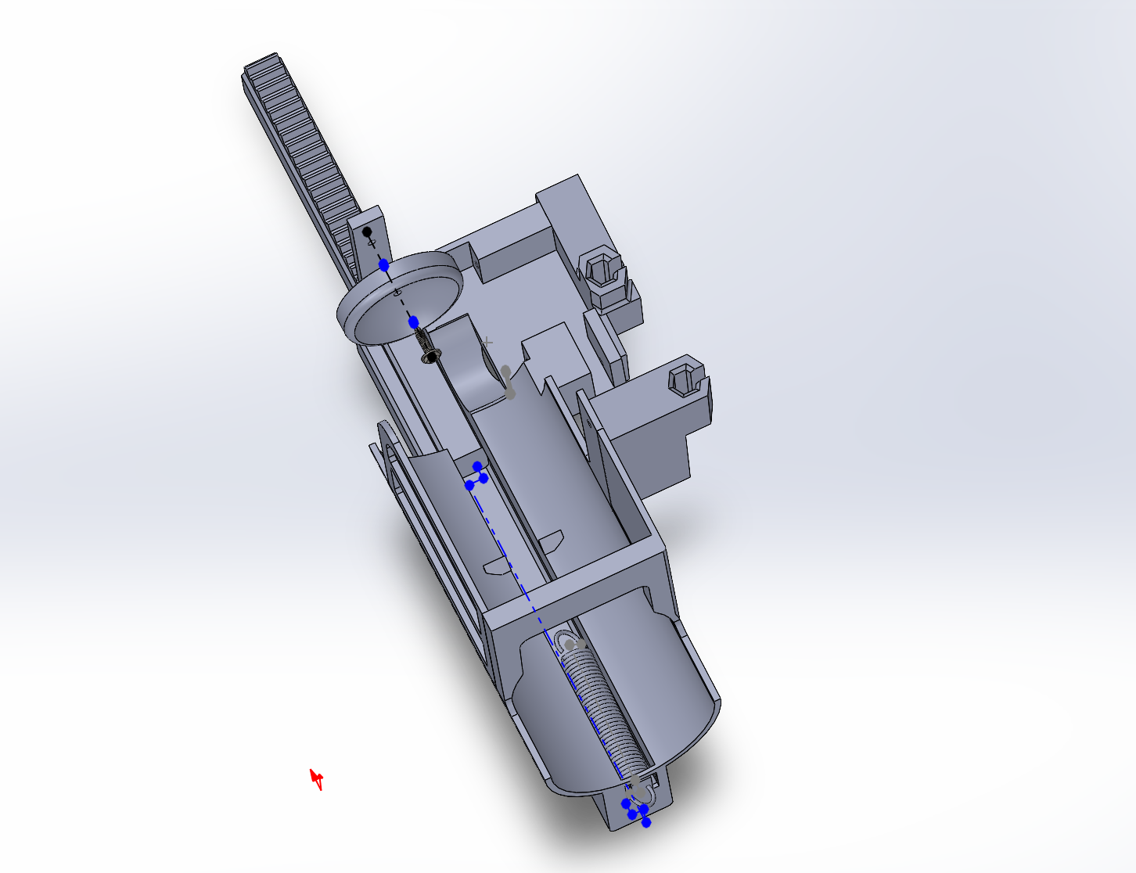
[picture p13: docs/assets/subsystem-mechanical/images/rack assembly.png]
rack assembly
  
</div>

5. Install MG90S and SG90S into respective mounts and secure using 2x M2.5x10. Attach servo cover over MG90S and secure using 2x rubber bands.

<div style="text-align: center;">
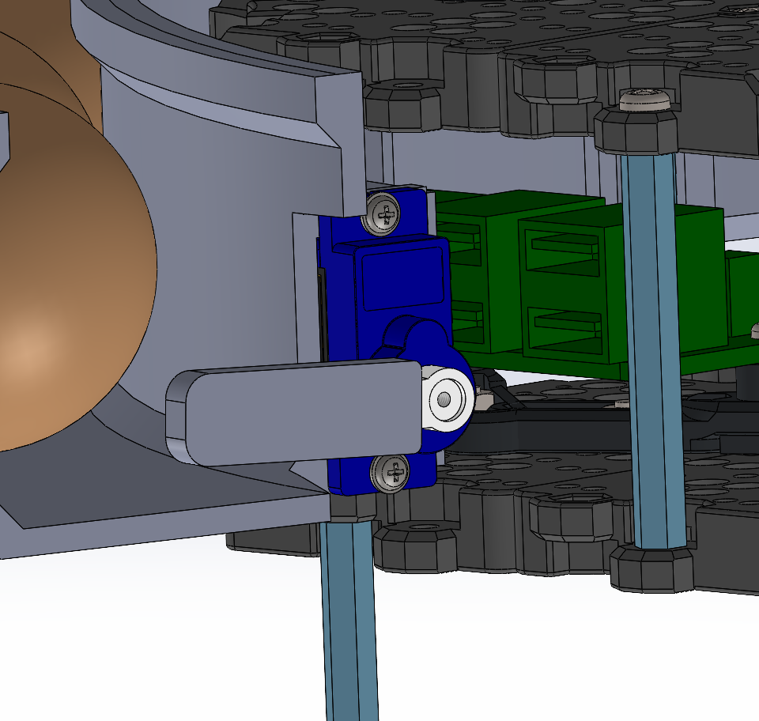
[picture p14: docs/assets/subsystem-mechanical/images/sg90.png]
sg90
  
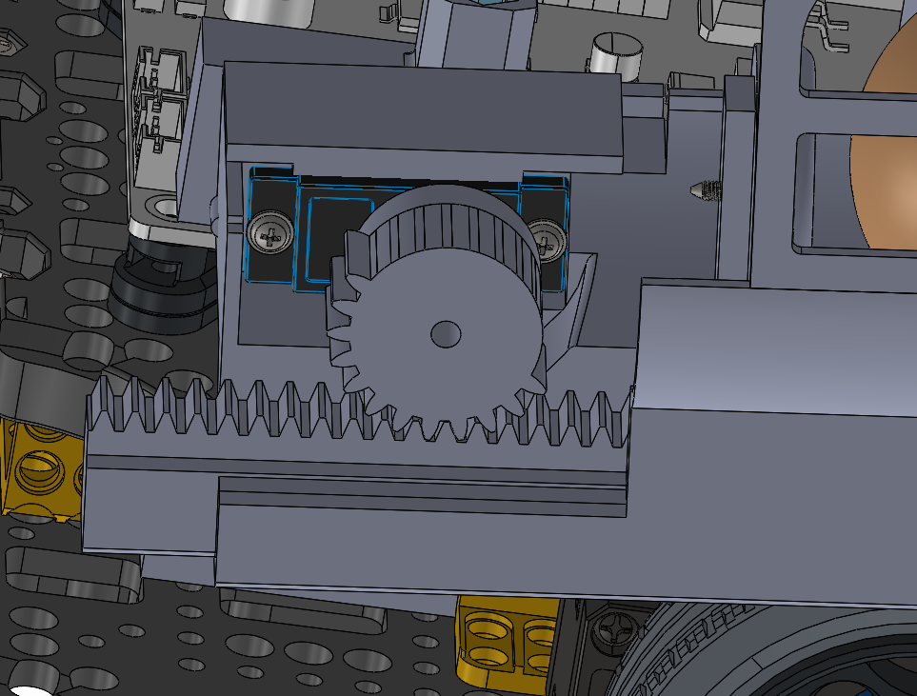
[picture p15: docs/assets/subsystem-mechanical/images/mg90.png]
mg90
   
</div>

6. Install detachable hex mounts to turtlebot hex standoffs.
<div style="text-align: center;">
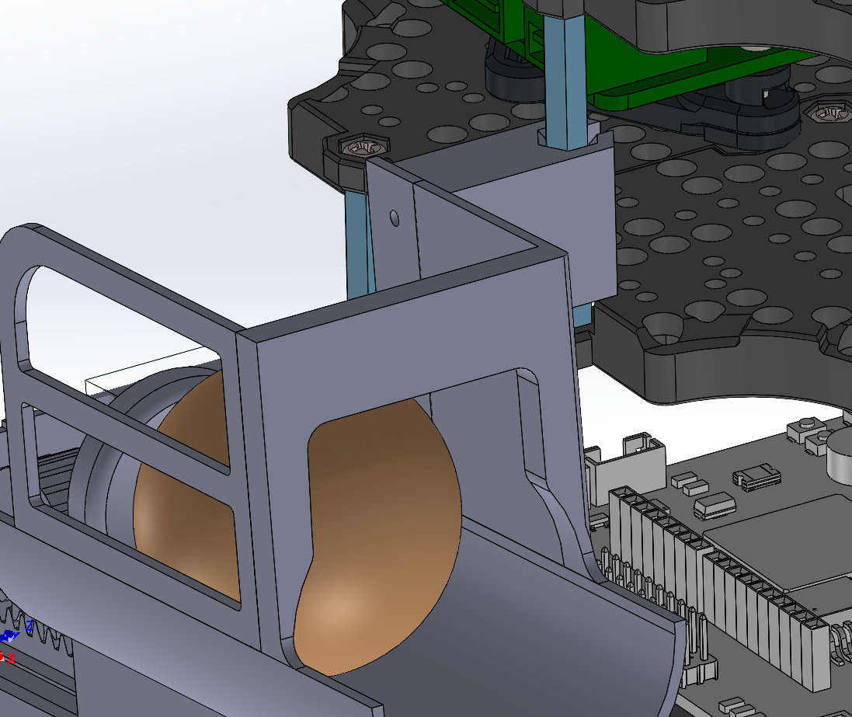
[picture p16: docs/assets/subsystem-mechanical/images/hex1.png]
hex1
  
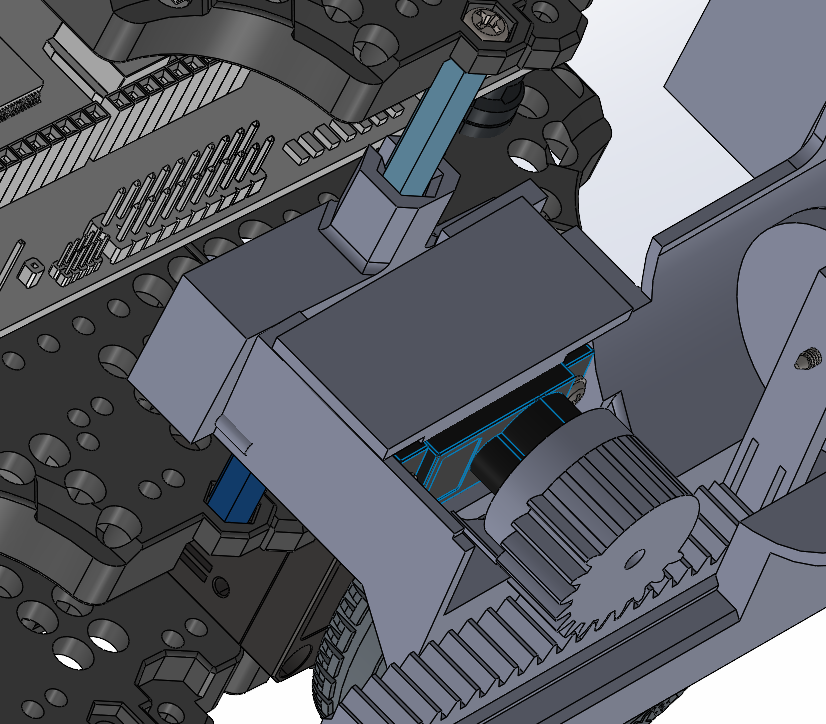
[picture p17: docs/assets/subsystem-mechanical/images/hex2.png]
hex2
   
</div>
7. Secure launcher main body into hex mounts using 2x M2x15.

<div style="text-align: center;">
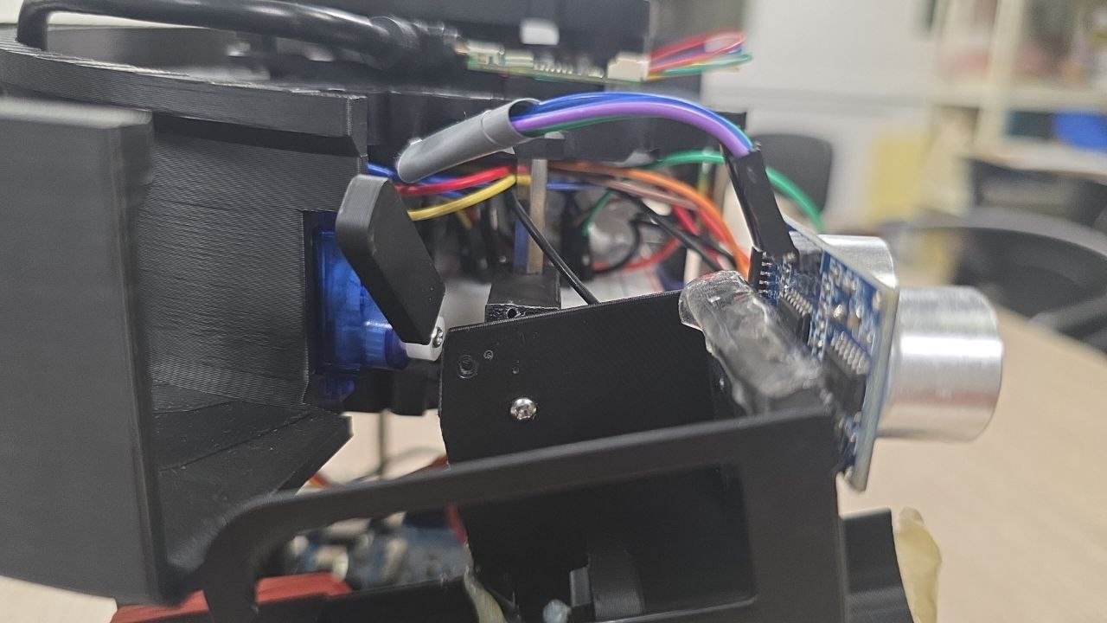
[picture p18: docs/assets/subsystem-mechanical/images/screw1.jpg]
screw1
  
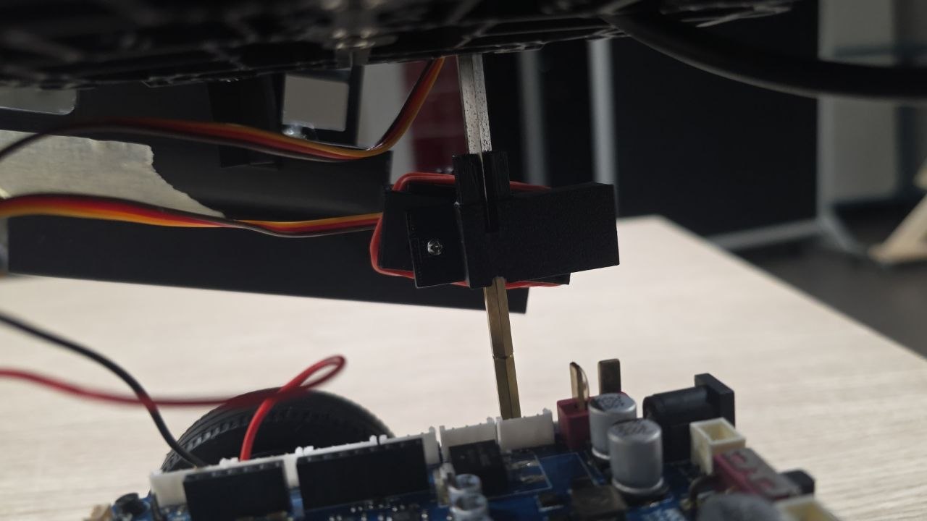
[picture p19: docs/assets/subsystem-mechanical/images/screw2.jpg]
screw2
   
</div>

8. Secure helix storage into hex standoffs.
<div style="text-align: center;">
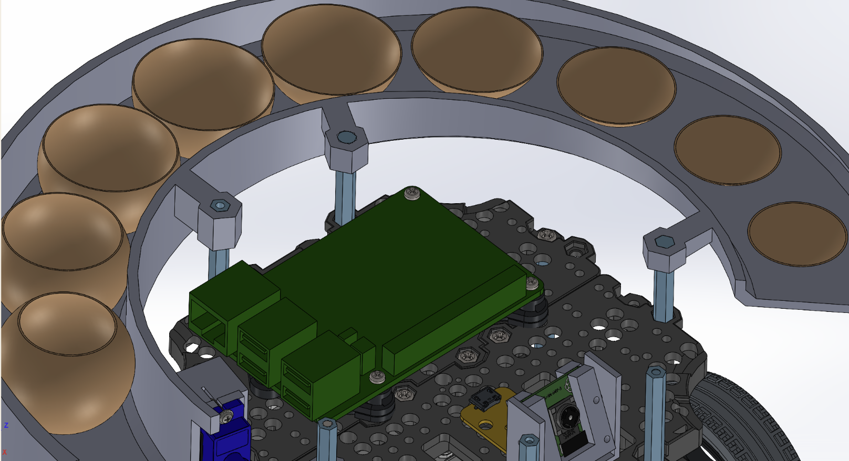
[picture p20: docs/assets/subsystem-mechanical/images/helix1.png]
helix1
  
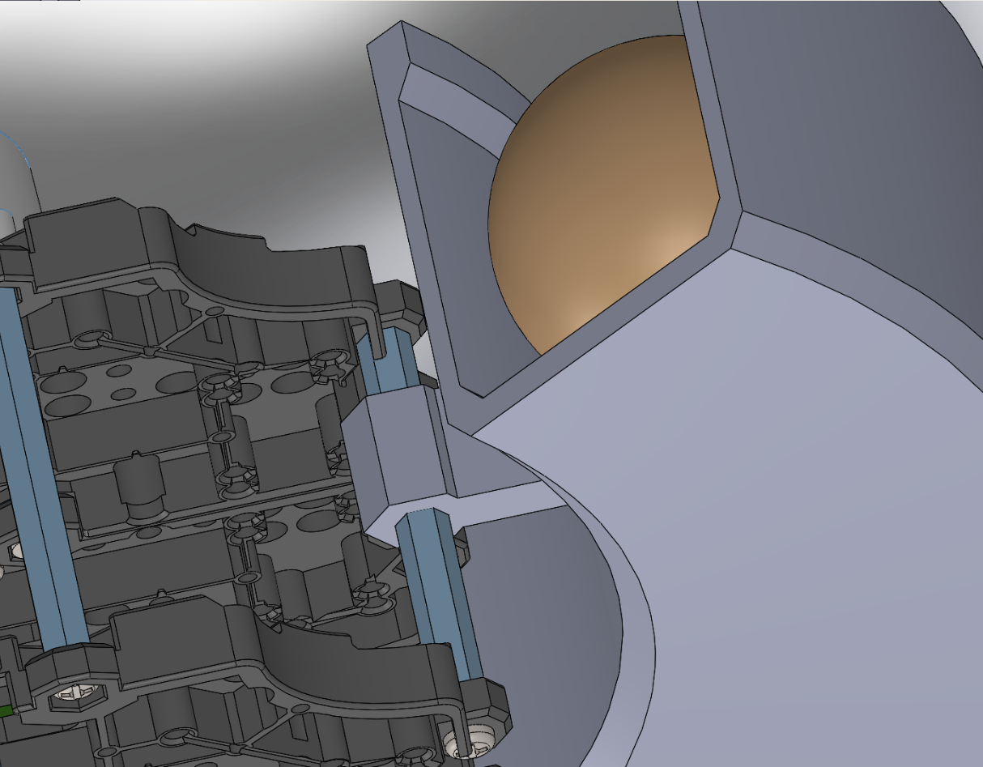
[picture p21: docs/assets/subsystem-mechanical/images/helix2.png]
helix2
   
</div>

9. Secure RPi Camera and mount into third waffle layer using 6x M2x15 screws, 6x M2 Nuts.
<div style="text-align: center;">
  RPi Camera
</div>

10. Attach HC-SR04 Ultrasonic sensor to front of launcher using double sided tape.
<div style="text-align: center;">
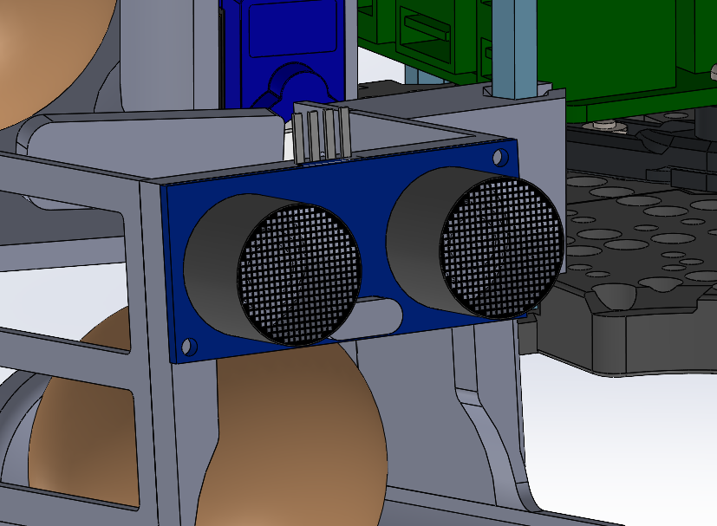
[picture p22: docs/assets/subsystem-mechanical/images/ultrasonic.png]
ultrasonic
  
</div>

11. Add hot glue along launcher wall (1x row along stop, 1x row in front of stop), 2x masking tape at front of launcher to act as paper gates.
<div style="text-align: center;">
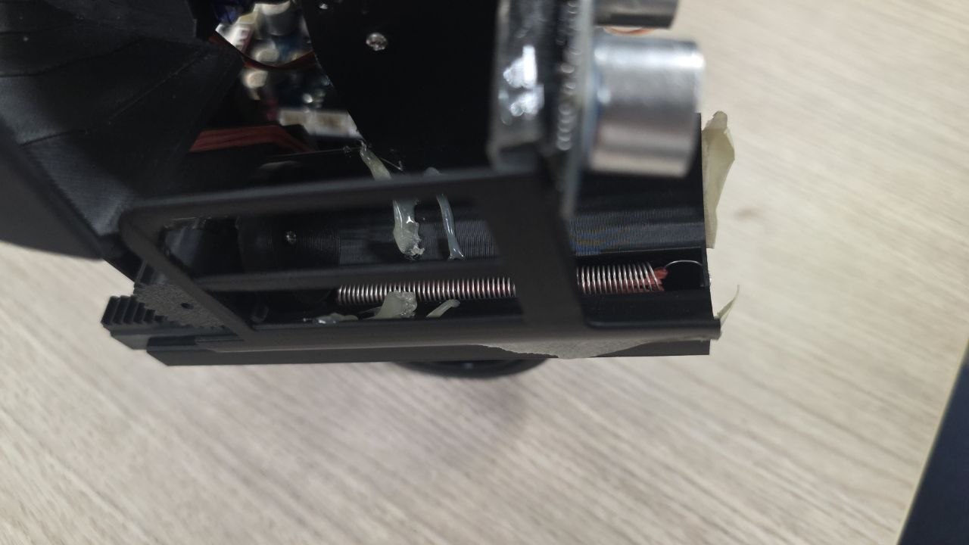
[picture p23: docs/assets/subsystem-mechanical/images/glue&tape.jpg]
  
</div>

## Build of Materials (BOM)

| Equipment | Qty | Price | Notes |
|---|---|---|---|
| 3D Printed Parts (Helix storage, Launcher, RPi Camera Mount) | - | $50 | Includes rack, pinion, servo mounts, hex mounts, conical pusher |
| MG90S Continuous Rotation Servo | 1 | $4.91 | Launcher rack-and-pinion actuation - [Source](https://shopee.sg/product/203724137/24136009312) |
| Spring | 1 | LAB | Launcher tension element |
| Logic Level Shifter | 1 | LAB | GPIO signal conditioning for servo and sensor |
| Electrical Components (Resistors, connectors) | - | LAB | Signal conditioning and wiring |
| M2x15 Screws | 9 | LAB | Fastening rack (1), launcher hex mounts (2), and camera mount (6) |
| M2 Nuts | 7 | LAB | Fastening with M2x15 screws (1 for rack, 6 for camera) |
| M2.5x10 Self-tapping Screws | 4 | LAB | MG90S and SG90S servo mount attachment (2 each) |
| M2.5x5 Screws | 2 | LAB | Servo horn attachment to MG90S (1) and SG90S (1) |
| Single Arm Servo Horns | 2 | LAB | Modified for MG90S pinion (1), SG90S helix storage gate (1) |
| Rubber Bands | 3 | LAB | Launcher tensioning (1) and servo cover attachment (2) |
| TurtleBot3 Burger Kit | 1 | LAB | Base robot platform |
| HC-SR04 Ultrasonic Sensor | 1 | LAB | Distance detection for receptacle |
| Double-sided Tape | - | LAB | Ultrasonic sensor mounting |
| Hot Glue | - | LAB | Launcher wall reinforcement |
| Masking Tape | - | LAB | Paper gates at launcher exit |
| RPi Camera V2.1 | 1 | GIVEN | ArUco marker detection |
| SG90 Standard Servo | 1 | GIVEN | Helix storage gate control |

## Actuator Mechanics

The launcher mechanism is a **rotary-to-linear transmission** where servo torque is translated through pinion teeth into rack displacement. The system consists of a synchronized servo-driven architecture with two key actors: the **rack servo** (continuous rotation) and the **gate servo** (standard). The system operates in a coordinated multi-step cycle to ensure repeatable, collision-free ball loading and launch.

### Mechanism Overview

- **Rack Servo (MG90S Continuous)**: Controls the horizontal pusher (rack) motion via pinion-to-rack gear mesh. Engagement pulls the rack backward (pressurizing the spring); disengagement releases the rack forward to launch the ball.
- **Gate Servo (SG90 Standard)**: Controls the binary gate mechanism. Opening allows a ball to drop into the launch channel; closing traps the ball in the launcher for the ensuing rack release.

### Full Delivery Cycle (Static & Dynamic)

#### Phase 1: Engage Rack (Pullback & Load)

1. Send continuous servo signal to **pinion servo** (engagement pulse width: ~1000–1300 µs depending on profile).
2. Hold engagement for **engagment duration** (~1s on mild profile) to pull the rack fully backward and compress the spring.
3. Move rack servo to **neutral position** (1500 µs pulse width) to stop motion.
4. Hold neutral for **rack_hold_duration** (~0.2 seconds) to stabilize the rack at maximum compression.
5. **Spring tension** is now stored; ball is ready to be fed into the launcher.

#### Phase 2: Gate Open (Feed Ball)

1. After a configurable offset from engage start (default: 0.35 seconds), send signal to **gate servo** to open position (gate_open_us: 500 µs).
2. Wait **gate_settle_s** (~0.225 seconds) for the gate mechanism to fully open and ball to drop from helix storage into the channel.
3. Ball is now positioned in the launcher channel at the pusher contact point.

**Synchronization note:** The offset between engage start and gate open ensures the spring is under tension before the ball arrives, preventing premature or inconsistent feed behavior.

#### Phase 3: Close Gate (Trap Ball)

1. Send signal to **gate servo** to closed position (gate_close_us: 1000 µs).
2. Wait **gate_settle_s** (~0.225 seconds) for gate to fully close. 
3. Timing is tuned such that only 1 ball is loaded into launcher.

#### Phase 4: Release Rack (Launch)

1. Wait **close_to_release_s** (~0.03125 seconds) to ensure gate closure is stable before launch impulse.
2. Send continuous servo signal to **pinion servo** to release position (1000 µs) to unlock and push the rack forward rapidly.
3. Rack travels forward, driven by spring and rubber band tension, pushing the ball into the launcher tube and out the exit opening.
4. Wait **disengage_pause** (cycle-dependent, e.g., 0.3 seconds base) to allow ball to fully exit and rack to settle.
5. Move rack servo back to **neutral position** (1500 µs) to complete the cycle.
6. **Next cycle can begin:** rack is reset and ready for re-engagement.

```mermaid
graph LR
  A[Trigger shot cycle] --> B[Start engage thread]
  B --> C{Parallel execution}
  C --> D[Thread: Rack pullback<br/>and compression]
  C --> E[Main: Wait offset<br/>and open gate]
  D --> F[Hold rack neutral]
  E --> G[Ball drop then<br/>close gate]
  F --> H[engage_thread.join]
  G --> H
  H --> I[Close to release delay]
  I --> J[Disengage rack<br/>Release]
  J --> K[Ball launched]
  K --> L[Reset rack neutral<br/>End cycle]
```
### Timing Dependencies & Profiles

The engagement profile (mild/medium/strong) adjusts the servo pulse width and duration:

| Profile | Engage Pulse (µs) | Engage Duration (s) | Use Case |
|---|---|---|---|
| Mild | 1000 | 1.0 | Light compression, shorter spring hold |
| Medium | 1200 | 1.4 | Balanced launch energy and reliability |
| Strong | 1300 | 1.52 | Maximum compression, maximum launch distance |

Mild profile is used in the final project version.

Additional timing parameters:
- **gate_settle_s** (~0.225 s): Delay after gate movement to allow mechanical settling.
- **ball_drop_s** (~0.225 s): Delay after gate opens to allow ball to fall into launcher channel.
- **close_to_release_s** (~0.03125 s): Delay after gate closes to stabilize before launch.
- **rack_hold_duration_s** (~0.2 s): Delay after rack reaches neutral to ensure stable compression hold.
- **rack_cycle_pause_s** (cycle-dependent): Delay after release to allow rack motion to settle before next cycle.

### Static Delivery (Timing Sequence):
Static delivery follows a fixed timing sequence:
1. First ball launched
2. 1 second wait
3. Second ball launched
4. 9 second wait
5. Third ball launched

### Dynamic Delivery (Two-Pass Mode)

For the dynamic delivery zone with moving receptacles:

**Pass 1 (Load):**
- Activates when target receptacle is first detected via ultrasonic sensor feedback (receptacle distance ≤ 0.70 m).
- Perform phases 1–3 (engage rack, open gate, close gate).
- **Skip phase 4:** Do NOT release the rack yet; ball remains loaded.
- Rack holds compressed state while waiting for receptacle approach.

**Pass 2 (Launch):**
- Perform phase 4 (release rack) when the target receptacle is detected for the second time at a optimal distance.
- Timing is triggered by ultrasonic sensor feedback.
- Ball launches into the moving receptacle with synchronized release.

### Full Delivery Cycle
<div style="display: flex; justify-content: center; margin: 2em 0;">
  <video width="360" height="360" controls>
    <source src="assets/subsystem-mechanical/videos/delivery.MP4" type="video/mp4">
    Your browser does not support the video tag.
  </video>
</div>

## Fabrication Plan & Materials

All custom mechanical parts were fabricated using 3D printing to support rapid prototyping and keep production cost low. Printing was carried out on the **Bambu Lab Carbon X1** and **Bambu Lab A1** using **PLA** as the default filament.

| Custom Part Group | Printer | Filament | Infill / Pattern | Purpose |
|---|---|---|---|---|
| Helix storage | Bambu Lab Carbon X1 / A1 | PLA | 10% infill with lightning infill pattern | Used to reduce material usage while maintaining sufficient strength for the storage section |
| Rack and pinion mechanism | Bambu Lab Carbon X1 / A1 | PLA | 40% infill with default infill pattern | Used to improve rigidity and wear resistance, reducing the risk of gear slipping |
| Launcher body | Bambu Lab Carbon X1 / A1 | PLA | 25% infill | Used to reduce launcher flex while keeping the part lightweight for repeated testing |
| Remaining custom parts | Bambu Lab Carbon X1 / A1 | PLA | Default print settings | Used for all remaining parts where additional reinforcement was not necessary |

Fabrication notes:

- All custom parts were printed in PLA using the default 3D printing filament.
- The helix storage uses lower infill because structural loads are comparatively low, allowing material usage to be reduced.
- The rack-and-pinion parts use higher infill to improve stiffness and reduce wear during repeated actuation.
- The launcher uses intermediate infill to limit flex under load without overbuilding the part.
- Default settings were used for the remaining parts to keep fabrication straightforward and consistent.

## Iterative Design Changes

| Issue Observed | Fixes Applied |
|---|---|
| Rack-pinion tolerance too tight and pinion wall interference | Removed the wall in the pinion-rack region to improve clearance |
| Pusher was taller than required | Reduced the pusher profile to prevent unnecessary interference |
| Launcher was difficult to service on the robot | Made the launcher detachable from the hex mounts for easier maintenance and rework |
| Ball drop into the launcher was inconsistent and tolerance was too tight | Moved the wall and stop further up to improve feed consistency |
| Launch distance was insufficient | • Increased gear teeth<br>• Added rubber bands with the spring for additional tensioning<br>• Made the pusher conical shaped for self-alignment of the ping pong ball during launch to prevent energy loss from hitting launcher walls |
| Gear slipping occurred under load | • Added the servo cover to secure the pinion servo tightly<br>• Lowered the servo height to improve gear engagement<br>• Reduced the servo screw hole diameter to lock the servo more firmly<br>• Increased wall thickness to reduce launcher flex under load |
| Ball could fall out laterally | Added a side wall to retain the ball during loading and launch |
| Ball rolling out of launcher before launch | • Made the launcher detachable from the hex mounts to tilt it upwards<br>• Added hot glue stops to prevent launcher jam from excessive ball rollback due to added tilt<br>• Added masking tape gates at the front of the launcher to further prevent ball rollout |

## Final Design & Validation

The final mechanical design adopts a detachable, servo-driven rack-and-pinion launcher with reinforced walls, tuned gear spacing, and improved retention geometry. Compared with early prototypes, the final configuration significantly improves feed reliability, removes slip events, and supports maintainable integration on the TurtleBot3.

<div style="display: flex; justify-content: center; margin: 2em 0;">
  <video width="360" height="480" controls>
    <source src="assets/subsystem-mechanical/videos/finaldesign.mp4" type="video/mp4">
    Your browser does not support the video tag.
  </video>
</div>

### Validation summary:
- Passed all Technical Performance Measures and Measures of effectiveness
- **18/18 successful consecutive launches** with **correct static delivery timing sequences**. 
- **No feeding or launcher jam errors**, all ping pong balls entered receptacle at **distance of 13cm from launcher**, significantly above required docking tolerance of 10cm from RPi Camera to ArUco marker

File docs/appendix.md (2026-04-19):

## 🔗 Navigation

- [Home](index.md)
- [Requirements Specification](requirements-specification.md)
- [Concept of Operations](con-ops.md)
- [High Level Design](high-level-design.md)
- [Software Subsystem: Navigation and FSM](subsystem-nav-fsm.md)
- [Software Subsystem: ArUco Marker Detection](subsystem-software-aruco.md)
- [Mechanical Subsystem](subsystem-mechanical.md)
- [Electrical Subsystem](subsystem-electrical.md)
- [Interface Control Document](interface-control-document.md)
- [Software and Firmware Development](software-firmware-development.md)
- [Testing Documentation](testing-documentation.md)
- [User Manual](user-manual.md)
- [Areas for Improvement](improvements.md)
- [Appendix](appendix.md)

---

# Appendix

## A. RViz Full Configuration Payload

This section preserves the full RViz payload  so teams can copy the exact configuration if needed.

Use it with:

```bash
cp ~/turtlebot3_ws/src/turtlebot3/turtlebot3_cartographer/rviz/tb3_cartographer.rviz ~/tb3_cartographer.rviz.backup
nano ~/turtlebot3_ws/src/turtlebot3/turtlebot3_cartographer/rviz/tb3_cartographer.rviz
```

Paste the payload below into `tb3_cartographer.rviz`:

```yaml
Panels:
  - Class: rviz_common/Displays
    Help Height: 78
    Name: Displays
    Property Tree Widget:
      Expanded:
        - /Global Options1
        - /LaserScan1/Topic1
      Splitter Ratio: 0.3916349709033966
    Tree Height: 347
  - Class: rviz_common/Selection
    Name: Selection
  - Class: rviz_common/Tool Properties
    Expanded:
      - /Publish Point1
      - /2D Pose Estimate1
    Name: Tool Properties
    Splitter Ratio: 0.5886790156364441
  - Class: rviz_common/Views
    Expanded:
      - /Current View1
    Name: Views
    Splitter Ratio: 0.5
Visualization Manager:
  Class: ""
  Displays:
    - Alpha: 0.5
      Cell Size: 1
      Class: rviz_default_plugins/Grid
      Color: 160; 160; 164
      Enabled: true
      Line Style:
        Line Width: 0.029999999329447746
        Value: Lines
      Name: Grid
      Normal Cell Count: 0
      Offset:
        X: 0
        Y: 0
        Z: 0
      Plane: XY
      Plane Cell Count: 10
      Reference Frame: <Fixed Frame>
      Value: true
    - Class: rviz_default_plugins/TF
      Enabled: true
      Frame Timeout: 15
      Frames:
        All Enabled: false
        base_footprint:
          Value: false
        base_link:
          Value: true
        base_scan:
          Value: false
        caster_back_link:
          Value: false
        imu_link:
          Value: false
        map:
          Value: false
        odom:
          Value: false
        wheel_left_link:
          Value: false
        wheel_right_link:
          Value: false
      Marker Scale: 1
      Name: TF
      Show Arrows: true
      Show Axes: true
      Show Names: true
      Tree:
        map:
          odom:
            base_footprint:
              base_link:
                base_scan:
                  {}
                caster_back_link:
                  {}
                imu_link:
                  {}
                wheel_left_link:
                  {}
                wheel_right_link:
                  {}
      Update Interval: 0
      Value: true
    - Alpha: 1
      Autocompute Intensity Bounds: true
      Autocompute Value Bounds:
        Max Value: 10
        Min Value: -10
        Value: true
      Axis: Z
      Channel Name: intensity
      Class: rviz_default_plugins/LaserScan
      Color: 255; 255; 255
      Color Transformer: Intensity
      Decay Time: 0
      Enabled: true
      Invert Rainbow: false
      Max Color: 255; 255; 255
      Max Intensity: 4439
      Min Color: 0; 0; 0
      Min Intensity: 105
      Name: LaserScan
      Position Transformer: XYZ
      Selectable: true
      Size (Pixels): 3
      Size (m): 0.019999999552965164
      Style: Boxes
      Topic:
        Depth: 50
        Durability Policy: Volatile
        Filter size: 10
        History Policy: Keep Last
        Reliability Policy: Best Effort 
        Value: /scan
      Use Fixed Frame: true
      Use rainbow: true
      Value: true
    - Angle Tolerance: 0.10000000149011612
      Class: rviz_default_plugins/Odometry
      Covariance:
        Orientation:
          Alpha: 0.5
          Color: 255; 255; 127
          Color Style: Unique
          Frame: Local
          Offset: 1
          Scale: 1
          Value: true
        Position:
          Alpha: 0.30000001192092896
          Color: 204; 51; 204
          Scale: 1
          Value: true
        Value: false
      Enabled: false
      Keep: 100
      Name: Odometry
      Position Tolerance: 0.10000000149011612
      Shape:
        Alpha: 1
        Axes Length: 1
        Axes Radius: 0.10000000149011612
        Color: 255; 25; 0
        Head Length: 0.30000001192092896
        Head Radius: 0.10000000149011612
        Shaft Length: 1
        Shaft Radius: 0.05000000074505806
        Value: Arrow
      Topic:
        Depth: 5
        Durability Policy: Volatile
        Filter size: 10
        History Policy: Keep Last
        Reliability Policy: Reliable
        Value: /odom
      Value: false
    - Alpha: 0.699999988079071
      Class: rviz_default_plugins/Map
      Color Scheme: map
      Draw Behind: false
      Enabled: true
      Name: Map
      Topic:
        Depth: 5
        Durability Policy: Transient Local
        Filter size: 10
        History Policy: Keep Last
        Reliability Policy: Reliable
        Value: /map
      Update Topic:
        Depth: 5
        Durability Policy: Transient Local
        History Policy: Keep Last
        Reliability Policy: Reliable
        Value: /map_updates
      Use Timestamp: false
      Value: true
    - Class: rviz_common/Group
      Displays:
        - Class: rviz_common/Group
          Displays:
            - Alpha: 0.699999988079071
              Class: rviz_default_plugins/Map
              Color Scheme: costmap
              Draw Behind: true
              Enabled: true
              Name: Map
              Topic:
                Depth: 5
                Durability Policy: Volatile
                Filter size: 10
                History Policy: Keep Last
                Reliability Policy: Reliable
                Value: /global_costmap/costmap
              Update Topic:
                Depth: 5
                Durability Policy: Volatile
                History Policy: Keep Last
                Reliability Policy: Reliable
                Value: /global_costmap/costmap_updates
              Use Timestamp: false
              Value: true
            - Alpha: 1
              Buffer Length: 1
              Class: rviz_default_plugins/Path
              Color: 255; 0; 0
              Enabled: true
              Head Diameter: 0.30000001192092896
              Head Length: 0.20000000298023224
              Length: 0.30000001192092896
              Line Style: Lines
              Line Width: 0.029999999329447746
              Name: Path
              Offset:
                X: 0
                Y: 0
                Z: 0
              Pose Color: 255; 85; 255
              Pose Style: None
              Radius: 0.029999999329447746
              Shaft Diameter: 0.10000000149011612
              Shaft Length: 0.10000000149011612
              Topic:
                Depth: 5
                Durability Policy: Volatile
                Filter size: 10
                History Policy: Keep Last
                Reliability Policy: Reliable
                Value: /global_plan
              Value: true
          Enabled: true
          Name: Global Map
        - Class: rviz_common/Group
          Displays:
            - Alpha: 1
              Class: rviz_default_plugins/Polygon
              Color: 25; 255; 0
              Enabled: true
              Name: Polygon
              Topic:
                Depth: 5
                Durability Policy: Volatile
                Filter size: 10
                History Policy: Keep Last
                Reliability Policy: Reliable
                Value: /local_costmap/footprint
              Value: true
            - Alpha: 0.699999988079071
              Class: rviz_default_plugins/Map
              Color Scheme: costmap
              Draw Behind: false
              Enabled: true
              Name: Map
              Topic:
                Depth: 5
                Durability Policy: Volatile
                Filter size: 10
                History Policy: Keep Last
                Reliability Policy: Reliable
                Value: /local_costmap/costmap
              Update Topic:
                Depth: 5
                Durability Policy: Volatile
                History Policy: Keep Last
                Reliability Policy: Reliable
                Value: /local_costmap/costmap_updates
              Use Timestamp: false
              Value: true
            - Alpha: 1
              Buffer Length: 1
              Class: rviz_default_plugins/Path
              Color: 255; 255; 0
              Enabled: true
              Head Diameter: 0.30000001192092896
              Head Length: 0.20000000298023224
              Length: 0.30000001192092896
              Line Style: Lines
              Line Width: 0.029999999329447746
              Name: Path
              Offset:
                X: 0
                Y: 0
                Z: 0
              Pose Color: 255; 85; 255
              Pose Style: None
              Radius: 0.029999999329447746
              Shaft Diameter: 0.10000000149011612
              Shaft Length: 0.10000000149011612
              Topic:
                Depth: 5
                Durability Policy: Volatile
                Filter size: 10
                History Policy: Keep Last
                Reliability Policy: Reliable
                Value: /local_plan
              Value: true
          Enabled: true
          Name: Local Map
        - Alpha: 1
          Arrow Length: 0.05000000074505806
          Axes Length: 0.30000001192092896
          Axes Radius: 0.009999999776482582
          Class: rviz_default_plugins/PoseArray
          Color: 0; 192; 0
          Enabled: true
          Head Length: 0.07000000029802322
          Head Radius: 0.029999999329447746
          Name: PoseArray
          Shaft Length: 0.23000000417232513
          Shaft Radius: 0.009999999776482582
          Shape: Arrow (Flat)
          Topic:
            Depth: 5
            Durability Policy: Volatile
            Filter size: 10
            History Policy: Keep Last
            Reliability Policy: Reliable
            Value: /particlecloud
          Value: true
      Enabled: false
      Name: Navigation
    - Class: rviz_common/Group
      Displays:
        - Alpha: 1
          Autocompute Intensity Bounds: true
          Autocompute Value Bounds:
            Max Value: 0.18203988671302795
            Min Value: 0.18195410072803497
            Value: true
          Axis: Z
          Channel Name: intensity
          Class: rviz_default_plugins/PointCloud2
          Color: 0; 255; 0
          Color Transformer: FlatColor
          Decay Time: 0
          Enabled: true
          Invert Rainbow: false
          Max Color: 255; 255; 255
          Max Intensity: 4096
          Min Color: 0; 0; 0
          Min Intensity: 0
          Name: scan_matched_points2
          Position Transformer: XYZ
          Selectable: true
          Size (Pixels): 3
          Size (m): 0.009999999776482582
          Style: Boxes
          Topic:
            Depth: 5
            Durability Policy: Volatile
            Filter size: 10
            History Policy: Keep Last
            Reliability Policy: Reliable
            Value: /scan_matched_points2
          Use Fixed Frame: true
          Use rainbow: true
          Value: true
        - Class: rviz_default_plugins/MarkerArray
          Enabled: false
          Name: Trajectories
          Namespaces:
            {}
          Topic:
            Depth: 5
            Durability Policy: Volatile
            History Policy: Keep Last
            Reliability Policy: Reliable
            Value: /trajectory_node_list
          Value: false
        - Class: rviz_default_plugins/MarkerArray
          Enabled: false
          Name: Constraints
          Namespaces:
            {}
          Topic:
            Depth: 5
            Durability Policy: Volatile
            History Policy: Keep Last
            Reliability Policy: Reliable
            Value: /constraint_list
          Value: false
        - Class: rviz_default_plugins/MarkerArray
          Enabled: false
          Name: Landmark Poses
          Namespaces:
            {}
          Topic:
            Depth: 5
            Durability Policy: Volatile
            History Policy: Keep Last
            Reliability Policy: Reliable
            Value: /landmark_poses_list
          Value: false
      Enabled: true
      Name: Cartographer
    - Alpha: 1
      Buffer Length: 1
      Class: rviz_default_plugins/Path
      Color: 0; 255; 255
      Enabled: true
      Head Diameter: 0.30000001192092896
      Head Length: 0.20000000298023224
      Length: 0.30000001192092896
      Line Style: Lines
      Line Width: 0.05000000074505806
      Name: Exploration Path
      Offset:
        X: 0
        Y: 0
        Z: 0
      Pose Color: 255; 85; 255
      Pose Style: None
      Radius: 0.029999999329447746
      Shaft Diameter: 0.10000000149011612
      Shaft Length: 0.10000000149011612
      Topic:
        Depth: 5
        Durability Policy: Volatile
        Filter size: 10
        History Policy: Keep Last
        Reliability Policy: Reliable
        Value: /exploration_path
      Value: true
  Enabled: true
  Global Options:
    Background Color: 48; 48; 48
    Fixed Frame: map
    Frame Rate: 10
  Name: root
  Tools:
    - Class: rviz_default_plugins/MoveCamera
    - Class: rviz_default_plugins/Select
    - Class: rviz_default_plugins/FocusCamera
    - Class: rviz_default_plugins/Measure
      Line color: 128; 128; 0
    - Class: rviz_default_plugins/SetGoal
      Topic:
        Depth: 5
        Durability Policy: Volatile
        History Policy: Keep Last
        Reliability Policy: Reliable
        Value: /move_base_simple/goal
    - Class: rviz_default_plugins/PublishPoint
      Single click: true
      Topic:
        Depth: 5
        Durability Policy: Volatile
        History Policy: Keep Last
        Reliability Policy: Reliable
        Value: /clicked_point
    - Class: rviz_default_plugins/SetInitialPose
      Covariance x: 0.25
      Covariance y: 0.25
      Covariance yaw: 0.06853891909122467
      Topic:
        Depth: 5
        Durability Policy: Volatile
        History Policy: Keep Last
        Reliability Policy: Reliable
        Value: initialpose
  Transformation:
    Current:
      Class: rviz_default_plugins/TF
  Value: true
  Views:
    Current:
      Angle: 0
      Class: rviz_default_plugins/TopDownOrtho
      Enable Stereo Rendering:
        Stereo Eye Separation: 0.05999999865889549
        Stereo Focal Distance: 1
        Swap Stereo Eyes: false
        Value: false
      Invert Z Axis: false
      Name: Current View
      Near Clip Distance: 0.009999999776482582
      Scale: 119.26066589355469
      Target Frame: <Fixed Frame>
      Value: TopDownOrtho (rviz_default_plugins)
      X: 0.0023878198117017746
      Y: -0.17037495970726013
    Saved: ~
Window Geometry:
  Displays:
    collapsed: false
  Height: 576
  Hide Left Dock: false
  Hide Right Dock: true
  QMainWindow State: 000000ff00000000fd00000004000000000000017a000001e6fc0200000008fb0000001200530065006c0065006300740069006f006e00000001e10000009b0000005c00fffffffb0000001e0054006f006f006c002000500072006f007000650072007400690065007302000001ed000001df00000185000000a3fb000000120056006900650077007300200054006f006f02000001df000002110000018500000122fb000000200054006f006f006c002000500072006f0070006500720074006900650073003203000002880000011d000002210000017afb000000100044006900730070006c006100790073010000003d000001e6000000c900fffffffb0000002000730065006c0065006300740069006f006e00200062007500660066006500720200000138000000aa0000023a00000294fb00000014005700690064006500530074006500720065006f02000000e6000000d2000003ee0000030bfb0000000c004b0069006e0065006300740200000186000001060000030c00000261000000010000010f00000236fc0200000003fb0000001e0054006f006f006c002000500072006f00700065007200740069006500730100000041000000780000000000000000fb0000000a00560069006500770073000000003d00000236000000a400fffffffb0000001200530065006c0065006300740069006f006e010000025a000000b200000000000000000000000200000490000000a9fc0100000001fb0000000a00560069006500770073030000004e00000080000002e10000019700000003000004420000003efc0100000002fb0000000800540069006d00650100000000000004420000000000000000fb0000000800540069006d00650100000000000004500000000000000000000002db000001e600000004000000040000000800000008fc0000000100000002000000010000000a0054006f006f006c00730100000000ffffffff0000000000000000
  Selection:
    collapsed: false
  Tool Properties:
    collapsed: false
  Views:
    collapsed: true
  Width: 1115
  X: 164
  Y: 106
```
## B. Calculated release height of ping pong ball
<div style="text-align: center;">
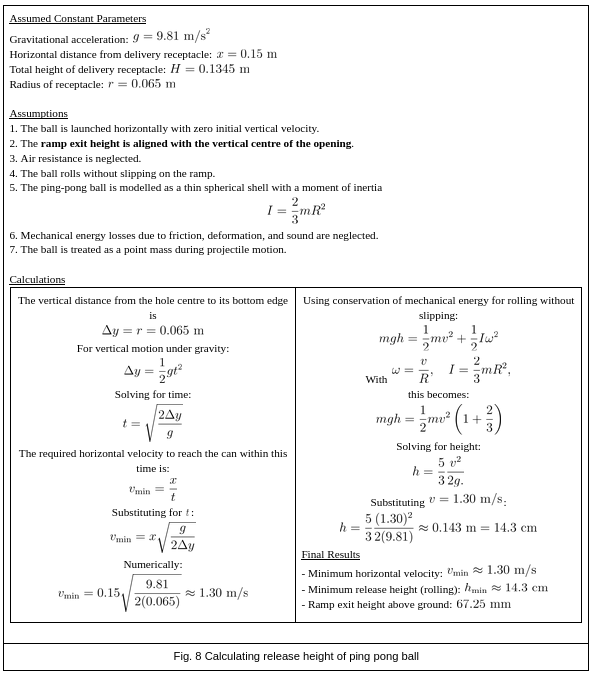
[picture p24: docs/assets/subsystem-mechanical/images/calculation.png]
calculation
  
</div>

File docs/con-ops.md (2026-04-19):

## 🔗 Navigation

- [Home](index.md)
- [Requirements Specification](requirements-specification.md)
- [Concept of Operations](con-ops.md)
- [High Level Design](high-level-design.md)
- [Software Subsystem: Navigation and FSM](subsystem-nav-fsm.md)
- [Software Subsystem: ArUco Marker Detection](subsystem-software-aruco.md)
- [Mechanical Subsystem](subsystem-mechanical.md)
- [Electrical Subsystem](subsystem-electrical.md)
- [Interface Control Document](interface-control-document.md)
- [Software and Firmware Development](software-firmware-development.md)
- [Testing Documentation](testing-documentation.md)
- [User Manual](user-manual.md)
- [Areas for Improvement](improvements.md)
- [Appendix](appendix.md)

---

# Concept of Operations

## Mission Context

The robot is an autonomous mobile robot (AMR) built on a TurtleBot3 Burger platform, designed to operate in a randomised, unknown warehouse-style arena. Its mission is to autonomously explore the environment, detect ArUco fiducial markers positioned near two delivery receptacles (one static, one dynamic), dock precisely in front of each receptacle, and deliver three ping-pong balls per receptacle using a rack-and-pinion launcher mechanism. The entire mission must be completed within a **25-minute execution window**.

There are two delivery zones:

- **Static receptacle** — a fixed delivery target identified by ArUco marker ID `0`.
- **Dynamic receptacle** — a moving delivery target identified by ArUco marker ID `1`, where an ultrasonic sensor is used to detect when the moving receptacle passes into range before triggering delivery.

The mission ends when both delivery zones have been serviced, or when the mission timer expires.

---

## System Overview

The robot integrates the following subsystems:

| Subsystem | Role |
|---|---|
| Navigation & SLAM | Frontier-based exploration using a 2D LiDAR occupancy grid |
| Finite State Machine (FSM) | Top-level mission orchestration and state arbitration |
| ArUco Marker Detection | Camera-based detection and 6-DOF pose estimation of delivery zone markers |
| Docking Controller | Precision alignment and approach to the detected marker |
| Shooter / Launcher | Sequential delivery of ping-pong balls into the receptacle |

All subsystems communicate over ROS 2 topics. The FSM acts as the central arbiter, consuming status signals from all subsystems and issuing state transitions accordingly.

---

## Normal Operating Scenario

1. The operator places the robot at the designated start position in the arena, loads 9 ping-pong balls into the tube, and ensures all hardware is powered and functioning.
2. The operator builds and sources the ROS 2 workspace, then launches the top-level bringup file for real hardware.
3. The robot boots into the `EXPLORE` state. Navigation begins autonomously — no further operator input is required during the mission.
4. As the robot explores, the camera continuously processes frames for ArUco markers. When a new, unvisited marker is detected, the FSM transitions to `DOCK`.
5. The docking controller aligns the robot perpendicularly in front of the marker and drives forward until the final proximity threshold is met.
6. On successful docking, the FSM transitions to `LAUNCH`. The shooter controller delivers three ping-pong balls into the receptacle.
   - For the **static receptacle**: three shots are fired with fixed inter-shot delays.
   - For the **dynamic receptacle**: the ultrasonic sensor polls for the moving receptacle to enter range before each shot, synchronising delivery with receptacle position.
7. After the shooting sequence completes, the FSM transitions to `BACKUP` (the robot reverses for ~2 seconds to clear the delivery zone), then returns to `EXPLORE`.
8. Steps 4–7 repeat for the second delivery zone.
9. Once both markers have been visited and the map is fully explored, the FSM transitions to `END` and the robot halts.

---

## System Workflow Flowchart

```mermaid
flowchart TD
    A[Start / Mission Begin] --> B[Navigation / Explore]
    B --> C{Unvisited marker detected?}
    C -->|No| B
    C -->|Yes| D[Docking]
    D --> E{Docking successful?}
    E -->|No| B
    E -->|Yes| F[Launching]
    F --> G[Backup]
    G --> H{Both delivery zones completed and map fully explored?}
    H -->|No| B
    H -->|Yes| I[End Mission]
```

## Exploration Phase

- The navigation controller (`exploration_controller`) implements a **frontier-based exploration** strategy. The occupancy grid from SLAM is analysed to identify frontier cells — known free cells adjacent to unknown space.
- Frontiers are grouped and scored by a ratio of frontier size to path distance. The best frontier group is selected as the next navigation target.
- A B-spline is fitted to the A\* path for smooth traversal. A pure-pursuit controller tracks the path.
- Local obstacle avoidance (using LiDAR scan sectors) is layered on top of path following, with tunable avoidance distances.
- Exploration concludes when no new frontier groups remain, at which point `/map_explored` is published `True`.

---

## Marker Detection Phase

- The `aruco_pose_streamer` node subscribes to `/camera/image_raw` and processes every frame using OpenCV's ArUco detector with the `DICT_4X4_250` dictionary.
- Camera intrinsics are loaded from `/camera/camera_info`. A fallback pinhole model is used if intrinsics are invalid.
- When a marker is detected, its 6-DOF pose (translation vector `tvec` and rotation vector `rvec`) is estimated using `cv2.aruco.estimatePoseSingleMarkers`.
- The pose is broadcast as a TF transform (`aruco_marker_<id>`) and a `/marker_detected` signal (`Bool`) is published to the FSM.
- The FSM reads the marker's child frame ID suffix to determine the zone: `aruco_marker_0` → `static`, `aruco_marker_1` → `dynamic`.
- Each zone is tracked in `visited_markers`. Once a zone is marked as visited, further detections of that zone are ignored.

---

## Docking Phase

The docking controller (`docking_controller`) operates as an independent state machine with the following states:

| State | Behaviour |
|---|---|
| `IDLE` | Waits for FSM to signal `DOCK` and for a valid marker transform to be available. |
| `SEARCH` | Rotates in place until the marker is centred horizontally (`tx ≈ 0`). |
| `APPROACH_1` | Drives straight toward the marker until `tz < 0.30 m`. |
| `TURN_SIDE` | Rotates by `(π/2 − θ)` to begin the perpendicular approach manoeuvre. |
| `DRIVE_SIDE` | Drives laterally to reach the perpendicular line in front of the marker. |
| `TURN_FACE_MARKER` | Rotates to re-face the marker directly (`tx ≈ 0`). |
| `FINAL_APPROACH` | Drives straight toward the marker until `tz < 0.10 m` or front LiDAR reads `< 0.20 m`. |
| `DONE` | Stops motion, publishes `/dock_done = True`, returns to `IDLE`. |
| `ABORT` | Stops motion, publishes `/dock_done = False`, returns to `IDLE`. |
| `OBSTACLE_AVOIDANCE` | Temporarily overrides docking motion to clear a proximate obstacle. |
| `SPECIAL_SEARCH` | After obstacle avoidance, performs a 360° rotation scan to re-acquire the marker. |

**Watchdog conditions** (both trigger `ABORT`):

- Marker continuously invisible for **30 seconds** during any active docking state.
- Any single docking state active for more than **45 seconds**.

---

## Launcher / Shooter Phase

The `shooter_controller` node receives a `/shoot_type` command (`static` or `dynamic`) from the FSM on entering the `LAUNCH` state.

**Static delivery sequence:**

1. Shot 1 fires immediately.
2. A short delay (~0.1 s) separates shot 1 and shot 2.
3. A longer delay (~7.1 s) separates shot 2 and shot 3.

**Dynamic delivery sequence:** The ultrasonic sensor polls the distance to the moving receptacle at regular intervals. Each of the three shots follows a two-pass sequence:

- **Load pass**: the rack engages and the gate opens/closes to seat a ball.
- **Launch pass**: triggered only when the ultrasonic sensor reads `distance ≤ 0.70 m`, indicating the moving receptacle is within delivery range.

Each shot cycle uses a rack servo (continuous rotation) to pull back the launcher, a gate servo to release the ball, and timing parameters configured via ROS 2 parameters at launch time. Hardware actuation is gated by the `enable_hardware` parameter — when `False`, the node runs in simulation mode.

A minimum hold duration of **15 seconds** is enforced in the `LAUNCH` state before the FSM accepts a completion signal, ensuring all shots have time to execute.

---

## Post-Delivery Backup Phase

After the shooter signals completion, the FSM transitions to `BACKUP`. The robot reverses at `0.1 m/s` for **2 seconds** before returning to `EXPLORE`. This prevents the robot from immediately attempting to re-dock with the just-visited marker.

---

## Shutdown Sequence

1. Allow the mission to reach the `END` state naturally, or press `Ctrl+C` to interrupt all nodes.
2. Confirm the robot has stopped moving (`/cmd_vel` publishes zero-velocity).
3. Power down the TurtleBot3 motors and Raspberry Pi safely.
4. Remove any remaining ping-pong balls from the magazine before storing the robot.
5. Kill any stale ROS 2 daemon processes before the next run:
   ```bash
   ros2 daemon stop
   pkill -f ros2
   ```

---

## Fault / Recovery Scenarios

| Fault | Symptom | Response |
|---|---|---|
| Marker lost during docking | `docking_controller` logs "Marker lost" | Docking aborts (`/dock_done = False`); FSM returns to `EXPLORE` |
| Marker invisible > 30 s | Watchdog triggers in docking controller | State transitions to `ABORT` → `IDLE` |
| Docking state stalls > 45 s | Per-state watchdog fires | State transitions to `ABORT` → `IDLE` |
| Obstacle during docking | Front LiDAR reads within `robot_r` | `OBSTACLE_AVOIDANCE` activates; `SPECIAL_SEARCH` follows to re-acquire marker |
| Shooter hardware failure | `shooter_controller` logs error, publishes `/shoot_done = False` | FSM returns to `EXPLORE`; zone is not marked visited |
| No frontier groups found | Navigation publishes `/map_explored = True` | FSM checks marker count; transitions to `END` if both zones visited, else continues waiting |
| Ultrasonic sensor no-read | `_read_ultrasonic_distance_m` returns `None` | Dynamic delivery continues polling; no shot fires until a valid distance is read |
| Invalid camera intrinsics | `aruco_pose_streamer` logs fallback warning | Fallback pinhole model used; detection continues with reduced accuracy |
| SLAM map not ready | `exploration_controller` waits in loop | Navigation holds until `/map`, `/odom`, and `/scan` are all available |

---

## Operator Responsibilities

- Inspect and confirm all 9 ping-pong balls are correctly loaded into the magazine before launch.
- Confirm the `enable_hardware` parameter is set correctly (`True` for physical robot, `False` for simulation).
- Supply the correct launch file for the target environment (real hardware vs. Gazebo).
- Monitor `/rosout` and node logs for warnings during the early exploration phase.
- Do not intervene or manually move the robot once the mission has started; any physical interference may corrupt the SLAM map.
- Ensure the arena is set up as specified before starting the mission timer.

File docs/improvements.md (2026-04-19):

## 🔗 Navigation

- [Home](index.md)
- [Requirements Specification](requirements-specification.md)
- [Concept of Operations](con-ops.md)
- [High Level Design](high-level-design.md)
- [Software Subsystem: Navigation and FSM](subsystem-nav-fsm.md)
- [Software Subsystem: ArUco Marker Detection](subsystem-software-aruco.md)
- [Mechanical Subsystem](subsystem-mechanical.md)
- [Electrical Subsystem](subsystem-electrical.md)
- [Interface Control Document](interface-control-document.md)
- [Software and Firmware Development](software-firmware-development.md)
- [Testing Documentation](testing-documentation.md)
- [User Manual](user-manual.md)
- [Areas for Improvement](improvements.md)
- [Appendix](appendix.md)

---

# Areas for Improvement

## 1. Launcher subsystem performance issues

Issue:
Both launcher servos stopped working on the mission day and later revived unexpectedly, but no longer followed the expected timing sequence. Troubleshooting focused on isolating the fault to `shooter_controller.py` logic versus faulty PWM wiring, because servo motion became erratic and desynchronized. The issue remains unresolved; the current leading suspicion is a logic level shifter fault.

Improvement:
- Replace the logic level shifter and re-run timing validation tests.
- Re-verify PWM wiring integrity and connector stability under motion.
- Run isolated bench tests on launcher timing before full mission integration.

## 2. Map message drops

Issue:
The map loads on first boot but often stops loading on second boot. This behavior suggests a camera-process-related overload path where duplicate nodes and camera processes overwhelm the data stream to the laptop, preventing SLAM Toolbox from receiving stable map data. This was mitigated by running the cleanup scripts documented in software and firmware setup. LiDAR QoS was also adjusted to reliable.

Improvement:
- Enforce cleanup script execution before every run as a standard operating step.
- Add automated pre-launch checks for duplicate nodes and camera processes.
- Continue QoS tuning for LiDAR and map-related topics under hardware load.

## 3. Hardware-level uncertainty on OpenCR board

Issue:
Intermittent TF and odometry message drops were observed on real hardware, with message frequencies below healthy operating range. Map updates are also significantly slower than expected, and odometry data takes much longer to refresh than normal. This suggests a potential OpenCR-related hardware bottleneck or communication instability, but root cause is not yet fully verified.

Improvement:
- Run controlled diagnostics to compare OpenCR serial behavior across power levels and cable conditions.
- Log TF/odom frequency baselines and define hard restart thresholds in operations.
- Prepare a hardware replacement/verification path to confirm or eliminate OpenCR as the root cause.

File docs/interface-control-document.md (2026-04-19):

## 🔗 Navigation

- [Home](index.md)
- [Requirements Specification](requirements-specification.md)
- [Concept of Operations](con-ops.md)
- [High Level Design](high-level-design.md)
- [Software Subsystem: Navigation and FSM](subsystem-nav-fsm.md)
- [Software Subsystem: ArUco Marker Detection](subsystem-software-aruco.md)
- [Mechanical Subsystem](subsystem-mechanical.md)
- [Electrical Subsystem](subsystem-electrical.md)
- [Interface Control Document](interface-control-document.md)
- [Software and Firmware Development](software-firmware-development.md)
- [Testing Documentation](testing-documentation.md)
- [User Manual](user-manual.md)
- [Areas for Improvement](improvements.md)
- [Appendix](appendix.md)

---

# Interface Control Document

## Document Purpose

This is the **authoritative reference for system contracts**: ROS topic definitions, launch arguments, message types, timing specifications, and error handling. This document defines WHAT interfaces exist and HOW they behave.

**Other documentation references this document for specifications:**
- [software-firmware-development.md](software-firmware-development.md) - HOW to build, deploy, and troubleshoot
- [subsystem-nav-fsm.md](subsystem-nav-fsm.md) - HOW the navigation and FSM subsystems work

## Interface Scope

This document defines the launch arguments, ROS topics, and ownership boundaries used by the integrated `auto_explore` package.

## ROS Topics

### External Sensor & Base Topics

| Topic | Type | Primary Owner | Purpose |
|---|---|---|---|
| `/map` | `nav_msgs/msg/OccupancyGrid` | SLAM Toolbox | Global map updates from SLAM |
| `/odom` | `nav_msgs/msg/Odometry` | Robot base (TurtleBot3) | Robot pose and velocity estimates |
| `/scan` | `sensor_msgs/msg/LaserScan` | LiDAR sensor | Obstacle and frontier sensing data |
| `/tf` | `tf2_msgs/msg/TFMessage` | TF2 broadcast (SLAM Toolbox) | Coordinate frame transformations |
| `/camera/image_raw` | `sensor_msgs/msg/Image` | Camera | Raw camera image stream |
| `/camera/camera_info` | `sensor_msgs/msg/CameraInfo` | Camera | Camera intrinsic calibration data |

### Mission Control Topics

| Topic | Type | Primary Owner | Purpose |
|---|---|---|---|
| `/states` | `std_msgs/msg/String` | Mission controller | FSM state publication (EXPLORE, DOCK, LAUNCH, END) |
| `/shoot_type` | `std_msgs/msg/String` | Mission controller | Shooter trigger mode (static, dynamic, or idle) |
| `/cmd_vel` | `geometry_msgs/msg/Twist` | Mission controller | Composite base velocity command |

### Marker Detection Topics

| Topic | Type | Primary Owner | Purpose |
|---|---|---|---|
| `/aruco/debug` | `std_msgs/msg/String` | Pose publisher | Marker pose payload and debug data |
| `/marker_detected` | `std_msgs/msg/Bool` | Pose publisher | Boolean signal indicating marker visibility |

### Internal Subsystem Topics

| Topic | Type | Primary Owner | Purpose |
|---|---|---|---|
| `/cmd_vel_nav` | `geometry_msgs/msg/Twist` | Exploration controller | Velocity commands from frontier-based navigation |
| `/cmd_vel_docking` | `geometry_msgs/msg/Twist` | Docking controller | Velocity commands from docking behavior |
| `/map_explored` | `std_msgs/msg/Bool` | Exploration controller | Frontier exploration completion signal |
| `/exploration_path` | `nav_msgs/msg/Path` | Exploration controller | Planned frontier-based path for visualization |
| `/dock_done` | `std_msgs/msg/Bool` | Docking controller | Dock cycle completion signal |
| `/shoot_done` | `std_msgs/msg/Bool` | Shooter controller | Shooter execution completion signal |

## Message Types

Topic type contracts above are the runtime reference and should be revalidated after interface changes.

Message type summary:
- `std_msgs/msg/String` - Text payloads (mission states, shooter modes, debug data)
- `std_msgs/msg/Bool` - Binary completion/status signals
- `geometry_msgs/msg/Twist` - Velocity commands (linear and angular components)
- `nav_msgs/msg/OccupancyGrid` - Occupancy map from SLAM
- `nav_msgs/msg/Odometry` - Pose and velocity estimates
- `nav_msgs/msg/Path` - Planned path visualization
- `sensor_msgs/msg/LaserScan` - LiDAR range data
- `sensor_msgs/msg/Image` - Raw camera image
- `sensor_msgs/msg/CameraInfo` - Camera calibration parameters
- `tf2_msgs/msg/TFMessage` - TF2 coordinate frame broadcasts

## Publish / Subscribe Ownership

**Exploration Controller:**
- Publishes: `/cmd_vel_nav`, `/map_explored`, `/exploration_path`
- Subscribes to: `/map`, `/odom`, `/scan`

**Mission Controller (FSM):**
- Publishes: `/states`, `/shoot_type`, `/cmd_vel` (arbitrates nav and docking velocities)
- Subscribes to: `/dock_done`, `/shoot_done`, `/map_explored`, `/marker_detected`, `/tf`, `/cmd_vel_nav`, `/cmd_vel_docking`

**Docking Controller:**
- Publishes: `/cmd_vel_docking`, `/dock_done`
- Subscribes to: `/odom`, `/tf`, `/states`

**Shooter Controller:**
- Publishes: `/shoot_done`
- Subscribes to: `/shoot_type`

**Pose Publisher (ArUco marker detection):**
- Publishes: `/aruco/debug`, `/marker_detected`
- Subscribes to: `/camera/image_raw`, `/camera/camera_info`

**SLAM Toolbox:**
- Publishes: `/map`, `/tf` (map↔odom transforms)
- Subscribes to: `/scan`

## Launch Arguments

### Top-level integrated launcher (`global_bringup.py`)

- `use_sim_time` - Use simulation clock if `true`; use system wall time if `false`
- `enable_slam` - Enable SLAM Toolbox mapping (default: `true`)
- `enable_rviz` - Enable RViz visualization (default: `true`)
- `slam_params_file` - Path to SLAM config YAML
- `enable_fsm` - Enable mission FSM (default: `true`)
- `enable_navigation` - Enable frontier exploration controller (default: `true`)
- `enable_markers` - Enable ArUco marker detection (default: `true`)
- `enable_pose_publisher` - Enable pose publisher node (default: `true`)
- `enable_docking` - Enable docking controller (default: `true`)
- `enable_shooter` - Enable shooter controller (default: `true`)
- `shooter_enable_hardware` - Enable physical GPIO actuation for shooter (default: `false`)

### Controller launcher (`global_controller_bringup.py`)

Includes all controller toggles plus shooter tuning arguments:

- `use_sim_time`
- `nav_params_file` - Path to navigation/exploration parameter YAML
- `enable_fsm`, `enable_navigation`, `enable_markers`, `enable_pose_publisher`, `enable_docking`, `enable_shooter`, `shooter_enable_hardware`
- `shooter_pigpiod_host` - Raspberry Pi hostname/IP running pigpiod (default: `localhost`)
- `shooter_pigpiod_port` - pigpiod port (default: `8888`)
- `shooter_ultrasonic_trigger_pin` - GPIO pin for ultrasonic trigger (default: `23`)
- `shooter_ultrasonic_echo_pin` - GPIO pin for ultrasonic echo (default: `24`)
- `shooter_ultrasonic_distance_threshold_m` - Fire distance threshold (default: `0.20` m)
- `shooter_ultrasonic_simulated_distance_m` - Simulated distance when hardware disabled (default: `0.15` m)
- `shooter_engage_profile` - Rack engagement profile: `mild`, `medium`, `strong` (default: `medium`)

### Navigation launcher (`nav_bringup.py`)

- `use_sim_time`
- `enable_slam`
- `enable_rviz`
- `slam_params_file`
- `slam_start_delay_sec` - Delay before SLAM start to stabilize TF/scan (default: `10.0` s)
- `rviz_start_delay_sec` - Delay before RViz start to let SLAM initialize (default: `10.0` s)

### Important Propagation Note

`global_bringup.py` is the integrated entrypoint, but shooter tuning arguments are declared in `global_controller_bringup.py`. If host/ultrasonic tuning is required, launch the controller bringup directly or update argument forwarding in `global_bringup.py`.

For simulation, use shorter delays: `slam_start_delay_sec:=2.0`, `rviz_start_delay_sec:=2.0`.

## Timing and Rates

### Launch-Time Delays

These delays prevent TF2 and sensor startup races:

| Delay Parameter | Gazebo Default | Real Robot Default | Purpose |
|---|---|---|---|
| `slam_start_delay_sec` | 2.0 s | 10.0 s | Wait for TF publishers and scan to stabilize before SLAM initialization |
| `rviz_start_delay_sec` | 2.0 s | 10.0 s | Wait for SLAM to publish map before RViz starts |

**Rationale:** Gazebo clock advances instantly; real robots have slower hardware initialization.

### Control Loop Rates

| Node | Rate | Purpose |
|---|---|---|
| Exploration Controller | 10 Hz | Path planning and velocity command computation |
| Mission Controller (FSM) | 10 Hz | State machine and velocity arbitration |
| Docking Controller | 10 Hz | Docking sequence and marker tracking |
| Shooter Controller | 10 Hz | Trigger logic and status publishing |
| Pose Publisher | 30 Hz (camera dependent) | ArUco marker detection and pose estimation |
| SLAM Toolbox | 25-50 Hz | Map updates and TF broadcasting |

### Topic Publishing Frequencies

| Topic | Frequency | QoS Profile | Notes |
|---|---|---|---|
| `/map` | 1-5 Hz | Reliable | Updated when new scans are processed |
| `/odom` | 20-30 Hz | Best-effort (sensor QoS) | Matches LiDAR or encoder rate |
| `/scan` | 10-20 Hz | Best-effort (sensor QoS) | LiDAR scan rate |
| `/tf` | 25+ Hz | Varies | TF2 broadcasts at sensor rates |
| `/states` | 10 Hz | Reliable | FSM state transitions |
| `/cmd_vel`, `/cmd_vel_nav`, `/cmd_vel_docking` | 10 Hz | Reliable | Controller outputs |
| `/marker_detected`, `/dock_done`, `/shoot_done` | Event-driven | Reliable | Published on state change |

## Error and Fallback Behavior

### Missing `/map` (SLAM not running or failed)
- **Behavior:** Exploration controller halts, publishes zero velocity on `/cmd_vel_nav`
- **FSM Impact:** Remains in EXPLORE; `/map_explored` stays `false`
- **Recovery:** Restart SLAM Toolbox; verify `/map` topic appears within 15 seconds
- **User Action:** Check SLAM logs; confirm `/scan` is being published; verify LiDAR connectivity

### Missing `/odom` (Robot odometry unavailable)
- **Behavior:** Docking controller and exploration controller cannot localize; publish zero velocity
- **FSM Impact:** FSM cannot transition to DOCK; mission stalls
- **Recovery:** Restart TurtleBot3 bringup; verify robot base is running
- **User Action:** Check if `robot.launch.py` succeeded; verify `/tf` and `/odom` topics exist

### Missing `/scan` (LiDAR offline)
- **Behavior:** Exploration controller cannot detect obstacles; may plan unsafe paths
- **FSM Impact:** FSM remains in EXPLORE with zero velocity
- **Recovery:** Check LiDAR USB connection; restart LiDAR node; verify `/scan` reappears
- **User Action:** `ros2 node list | grep scan`; check LiDAR power and USB cable

### Missing `/camera/image_raw` or `/camera/camera_info`
- **Behavior:** Pose publisher fails silently; `/marker_detected` stays `false`
- **FSM Impact:** FSM never transitions from EXPLORE to DOCK
- **Recovery:** Restart camera node; verify topics under 5 seconds
- **User Action:** Check camera USB connection; run `ros2 run camera_ros camera_node` manually if needed

### Marker detection failure (marker not visible or poor lighting)
- **Behavior:** Pose publisher publishes `false` on `/marker_detected`
- **FSM Impact:** Mission loops in EXPLORE indefinitely
- **Recovery:** Adjust lighting; ensure ArUco marker is visible to camera; check marker size in launch args (`marker_size_m: 0.053`)
- **User Action:** Verify marker orientation; test with `ros2 run cv_bridge cv_bridge_demo_color`

### Docking controller failure
- **Behavior:** Robot cannot reach docking marker; `/dock_done` stays `false` for > 20s timeout
- **FSM Impact:** FSM times out after `dock_cycle_timeout_sec` (20s default); republishes state as DOCK
- **Recovery:** Disable docking (`enable_docking:=false`) to skip DOCK state; adjust timeout parameter
- **User Action:** Check docking marker visibility; verify robot can navigate to marker pose

### Shooter hardware unavailable
- **Behavior:** With `shooter_enable_hardware:=false`, shooter uses simulated distance; fires at threshold
- **FSM Impact:** Mission progresses normally; only firing is simulated
- **Recovery:** Set `shooter_enable_hardware:=true` to enable hardware GPIO; verify Raspberry Pi running `pigpiod`
- **User Action:** SSH to Pi; run `sudo pigpiod`; verify GPIO pins accessible; test with `pigs servo <pin> <value>`

## Interface Change Rules

### When to Update This Document

Update this document **before or immediately after** any of the following changes:

1. **Topic Addition/Removal/Rename:**
   - Add new row to appropriate ROS Topics section
   - Update Publish/Subscribe Ownership section
   - Update subsystem-nav-fsm.md and software-firmware-development.md references
   - Example: Adding `/base_status` topic → add to External Sensor Topics table

2. **Message Type Change:**
   - Example: Changing `/shoot_type` from `std_msgs/msg/String` to `std_msgs/msg/Int32`
   - Update ROS Topics table, Message Types section, and Publish/Subscribe Ownership
   - Verify all subscribers/publishers in code match new type

3. **Launch Argument Addition/Removal:**
   - Add/remove from appropriate launcher section
   - Document default value and purpose
   - Update software-firmware-development.md launch command examples
   - Example: Adding `exploration_max_iterations` → add to "Top-level integrated launcher"

4. **Control Loop Rate Change:**
   - Update Timing and Rates table
   - Document rationale in table notes
   - Verify message ordering and QoS profiles remain compatible

5. **Error Handling or Fallback Logic Change:**
   - Update corresponding entry in Error and Fallback Behavior section
   - Document new recovery procedures
   - Update troubleshooting guide in software-firmware-development.md

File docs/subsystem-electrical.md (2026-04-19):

## 🔗 Navigation

- [Home](index.md)
- [Requirements Specification](requirements-specification.md)
- [Concept of Operations](con-ops.md)
- [High Level Design](high-level-design.md)
- [Software Subsystem: Navigation and FSM](subsystem-nav-fsm.md)
- [Software Subsystem: ArUco Marker Detection](subsystem-software-aruco.md)
- [Mechanical Subsystem](subsystem-mechanical.md)
- [Electrical Subsystem](subsystem-electrical.md)
- [Interface Control Document](interface-control-document.md)
- [Software and Firmware Development](software-firmware-development.md)
- [Testing Documentation](testing-documentation.md)
- [User Manual](user-manual.md)
- [Areas for Improvement](improvements.md)
- [Appendix](appendix.md)

---
# Electrical Subsystem

## 1. Problem Description
- Integrate SG90 and MG90S servo motors for the launching mechanism into the Turtlebot3 Burger's existing electrical system.
- Integrate HC-SR04 ultrasonic sensor (added later) to detect the moving receptacle.
- Ensure all additions operate within component ratings without disrupting the base Turtlebot3 setup.

## 2. Design Requirements
- System must sustain at least 25 minutes of continuous operation per charge.
- All components must operate within rated voltage and current limits.
- Current draw must remain within the battery's maximum safe discharge current (C-rate limit).
- No unintended actuation of servos or drive motors on startup.

## 3. Power Budget

### Battery
- Voltage: 11.1V  |  Capacity: 1.8 Ah  |  C-Rate: 5C  
- Max safe discharge current: $1.8 \times 5 = 9A$  
- Total usable energy (80% efficiency):  
  $11.1 \times 1.8 \times 0.8 = 15.984 \text{ Wh} = 57,542.4 \text{ J}$  

### Worst Case Power Budget Table

| Component | Voltage (V) | Current (A) | Max Power (W) |
|---|---|---|---|
| SG90 Servo Motor | 5 | 0.36 (stall) | 1.8 (stall) |
| MG90S Servo Motor | 5 | 0.8 (stall) | 4 (stall) |
| HC-SR04 Ultrasonic | 5 | 0.015 (operational) | 0.075 (operational) |
| BOB-11978 Level Shifter | 3.3 | ~0 | ~0 |
| Turtlebot (Movement) | 11.1 | 0.94 (surge) | 10.439 (surge) |
| RPi Camera v2 | 3.3 | 0.35 (surge) | 1.15 (surge) |

$$
\text{Operation Time} = \frac{57542.4}{(1.8 + 4 + 0.075 + 10.439 + 1.15)} = 3294.9 \text{ s} \approx 54.9 \text{ minutes}
$$

### Mission Duration Feasibility
- Required mission duration: 25 minutes  
- Worst-case runtime: ~54.9 minutes → ~2 full missions possible  
- Battery is sufficient even when all components draw maximum power simultaneously.  

## 4. Electrical Subsystem Connections

The electrical subsystem integrates sensor feedback, PWM servo and ultrasonic sensor control, and power distribution for the launcher mechanism and TurtleBot3 operations as shown below:

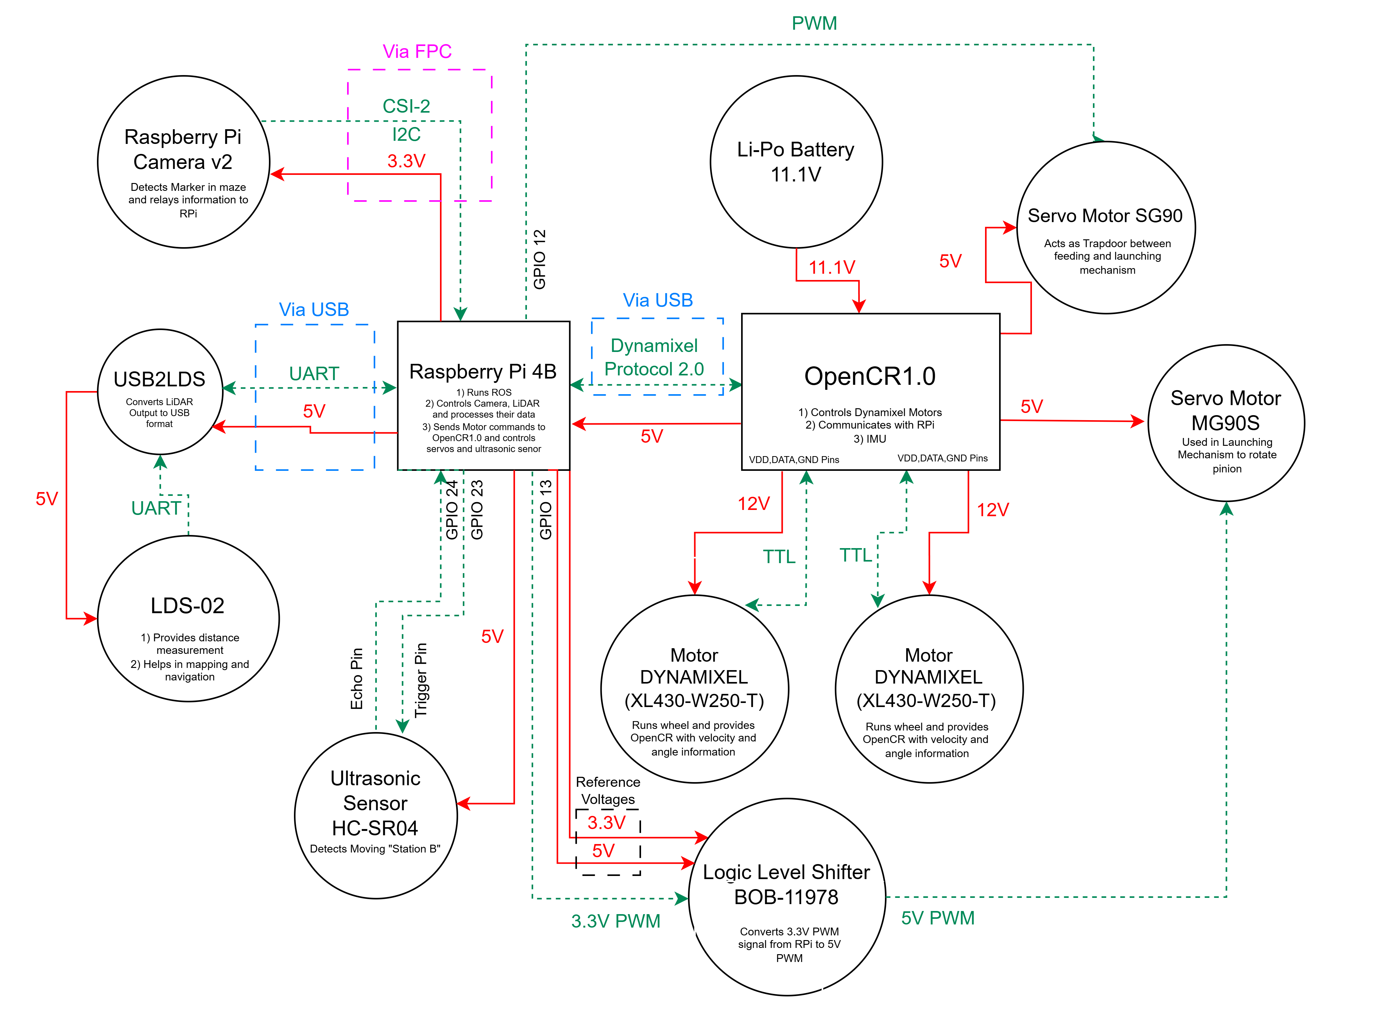
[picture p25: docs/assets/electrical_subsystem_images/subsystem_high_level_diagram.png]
Electrical Subsystem


_High Level Electrical System Design_

Electrical Schematic 

_Electrical Schematic Diagram_

### Power Wiring
- 11.1V Li-Po → OpenCR1.0 and Turtlebot base.
- OpenCR 5V/4A pin → terminal block → RPi 4B, SG90, MG90S.

Terminal Block Connections

_Terminal Block_

- RPi 5V power pin → HC-SR04.
- RPi 3.3V rail → BOB-11978 (LV reference); OpenCR 5V → BOB-11978 (HV reference).
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

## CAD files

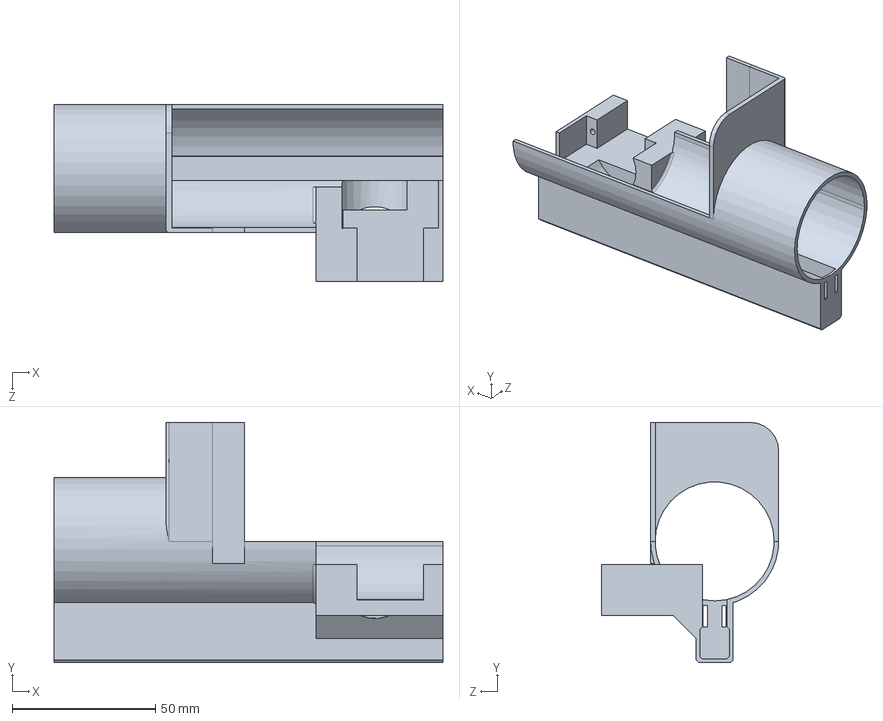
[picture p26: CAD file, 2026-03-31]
CAD/misc/reference/launcher-main-body-fastener2.SLDPRT
136.0 x 84.0 x 62.0 mm

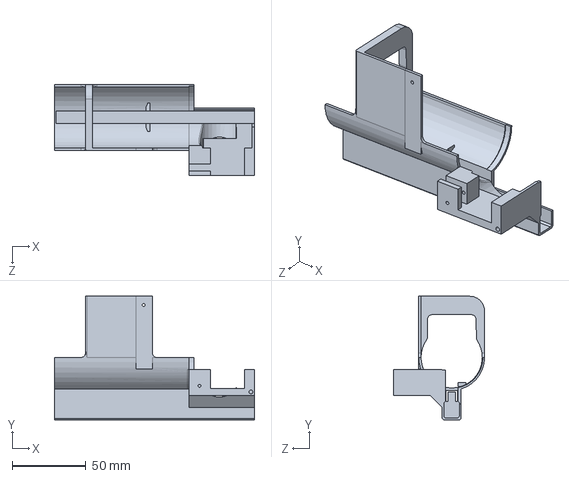
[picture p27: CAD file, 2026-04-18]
CAD/misc/past-iterations/launcher-main-body-v3.SLDPRT
136.0 x 84.0 x 62.0 mm

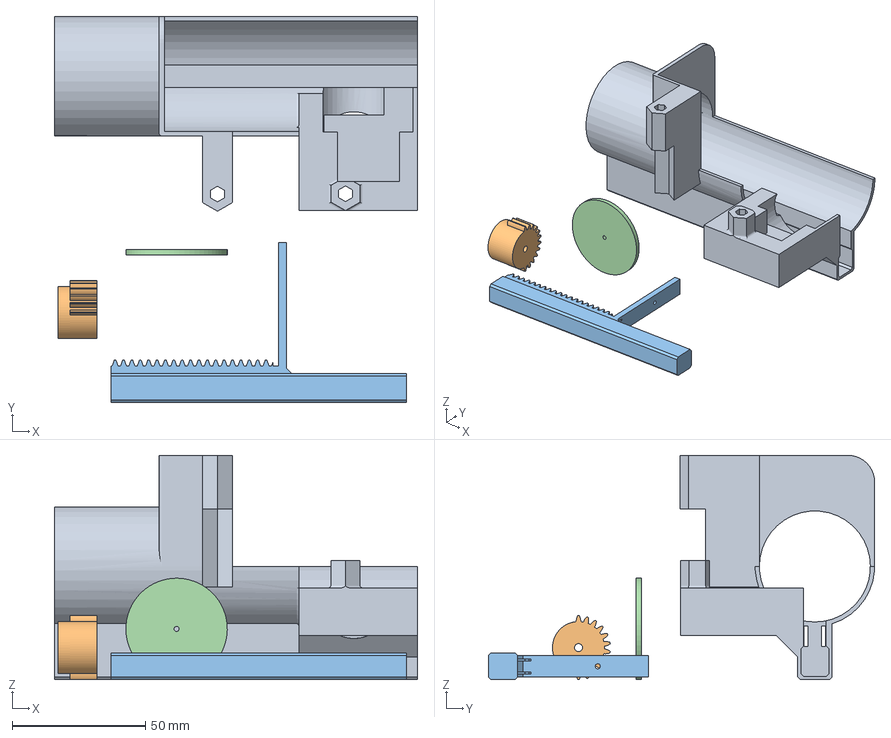
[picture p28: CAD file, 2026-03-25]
CAD/misc/slicer/launcher-main-body.3mf
136.0 x 144.8 x 84.0 mm
launcher-main-body.STL
pinion gear assembly-as-part-v2.STL
rack-as-part-v2.STL
launcher-pusher.STL

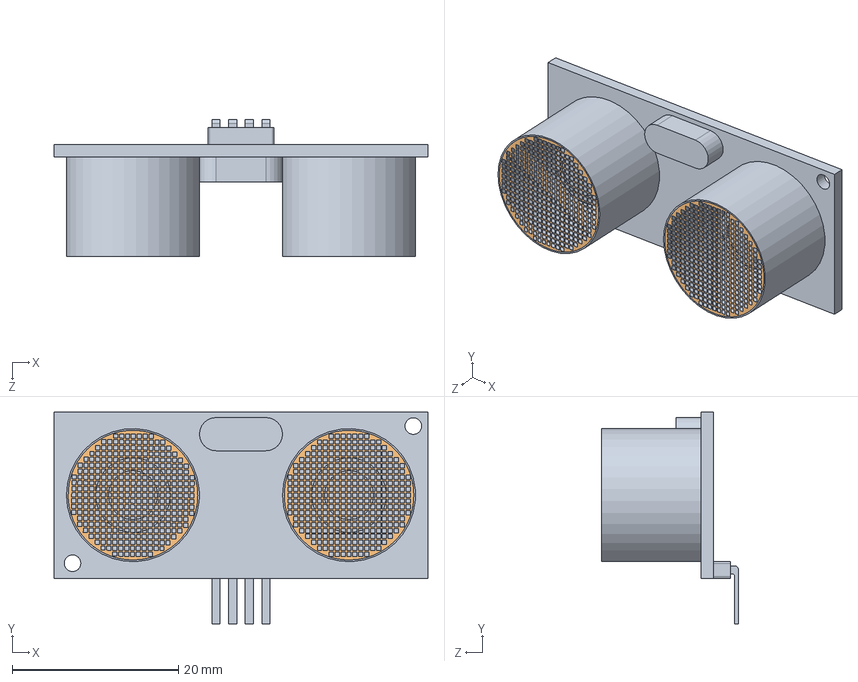
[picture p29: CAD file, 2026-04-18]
CAD/Turtlebot Assembly/hc-sr04-16.snapshot.15/HC-SR04/HCSR04FINAL.SLDASM
45.0 x 25.5 x 16.5 mm
HC-SR04
RED x 2

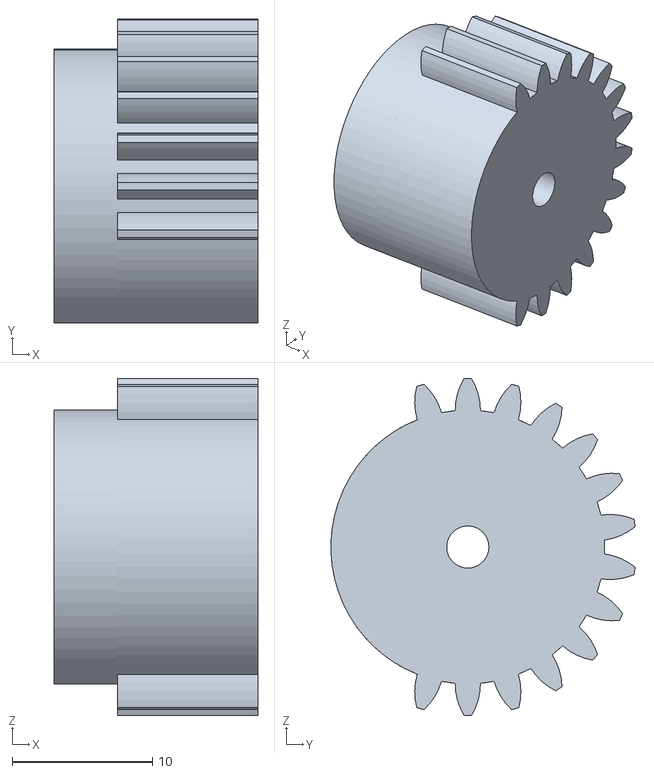
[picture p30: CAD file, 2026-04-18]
CAD/misc/stl files/past iterations/pinion gear assembly-as-part-v3.STL
14.5 x 21.7 x 24.0

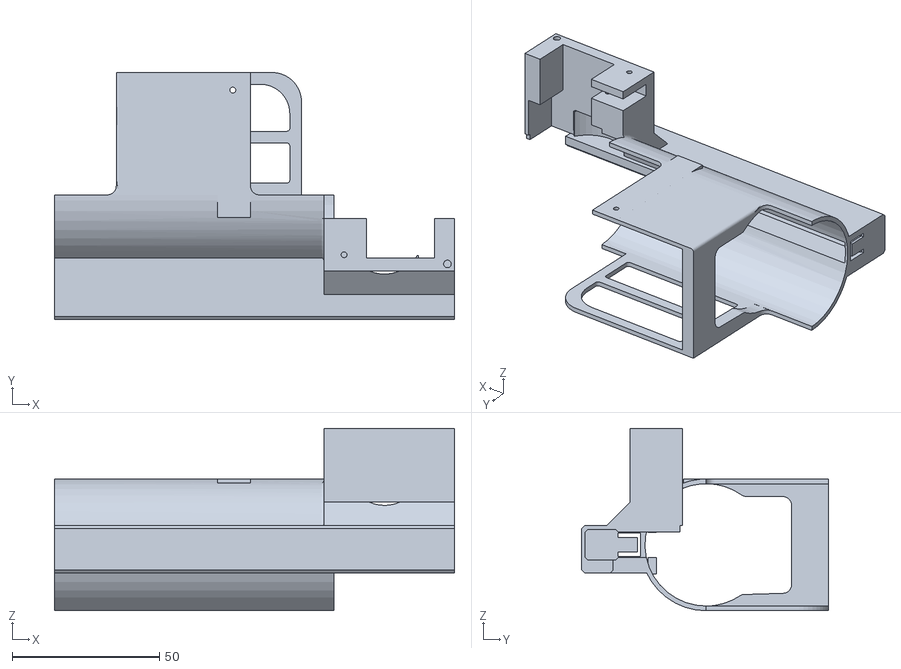
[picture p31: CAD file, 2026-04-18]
CAD/misc/stl files/past iterations/launcher-main-body-v4.STL
136.0 x 84.0 x 62.0

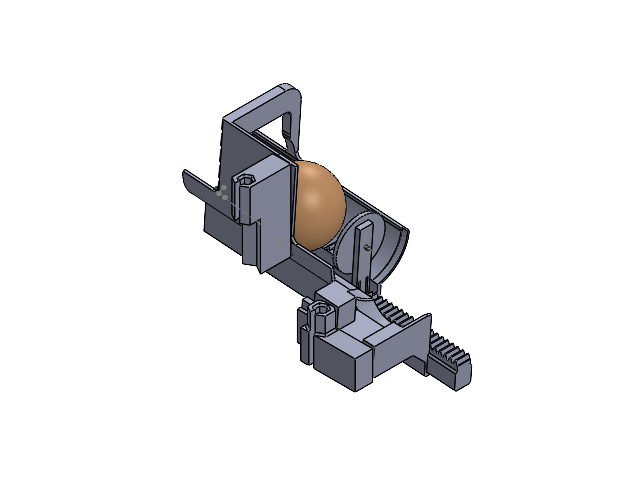
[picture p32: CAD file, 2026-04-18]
CAD/misc/past-iterations/launcher-assembly-v2.SLDASM
rack-as-part-v2
pingpong
SG90 - Micro Servo 9g - Tower Pro.5
launcher-pusher
spring
launcher-main-body-fastener2
launcher-main-body-fastener1
launcher-main-body-v3

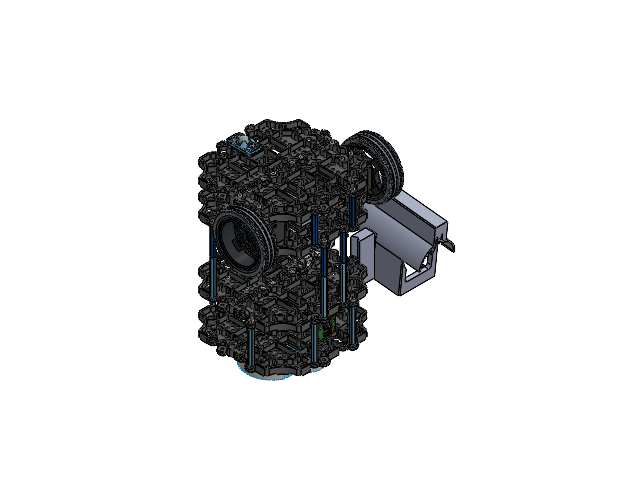
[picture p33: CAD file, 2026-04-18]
CAD/Turtlebot Assembly/Turtlebot Assembly with payload-v2.SLDASM
STEELBALL_3_8INCH
PR21_CASTER_CVR_3X5_REV6
P30_ISP_A001_3D x 2
PR16_A01_TIRE_2 x 2
M_PR07_A01_BRACKET_2 x 5
SUPPORT_HEX_M3_0XL35_FF x 8
Waffle Plate x 8
pan cross head_ks x 89
hexagon nut style 1 gradeab_ks x 28
LB-012 Battery
PR30_IBB_01_3D x 8
OPENCR Dummy
SUPPORT_HEX_M3_0XL45_FF-9 x 6
PR30_IBB_01_3D-10 x 4
Raspberry_Dummy
MICRO_USB
MICRO_USB-3
MICRO_USB-4
MICRO_USB-5
MICRO_USB-6
BIC04_C01_PCB
MICRO_USB-8
SUPPORT_HEX_M3_0XL45_FF x 4
M_PR07_A01_SPACER_RIVET x 4
LDS Dummy
pinion gear assembly-as-part-v2
pinion-servo-horn-attachment-for-gear
Tower Pro MG90S Micro servo
SG90 - Micro Servo 9g - Tower Pro.5 x 3
Cam V2.1 v1
rpi camera mount v2
rpi camera stand v2
rack-as-part-v2
pingpong
launcher-pusher-v2
spring
launcher-main-body-fastener2
launcher-main-body-fastener1
launcher-main-body-v4
servo-cover

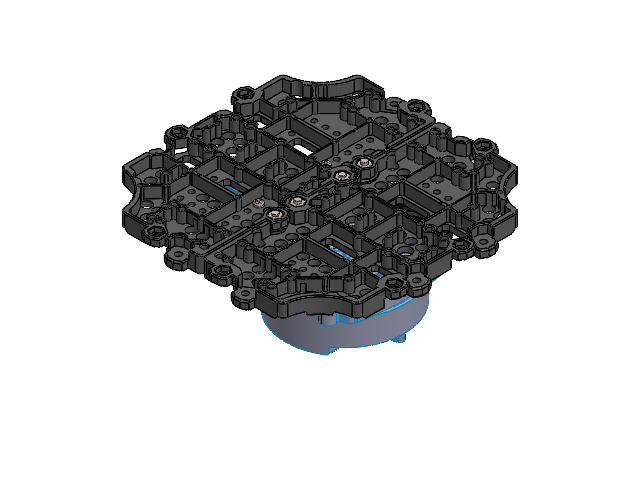
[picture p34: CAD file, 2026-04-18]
CAD/Turtlebot Assembly/Fourth Layer.SLDASM
Waffle Plate x 2
pan cross head_ks x 12
hexagon nut style 1 gradeab_ks x 8
PR30_IBB_01_3D x 4
M_PR07_A01_SPACER_RIVET x 4
LDS Dummy

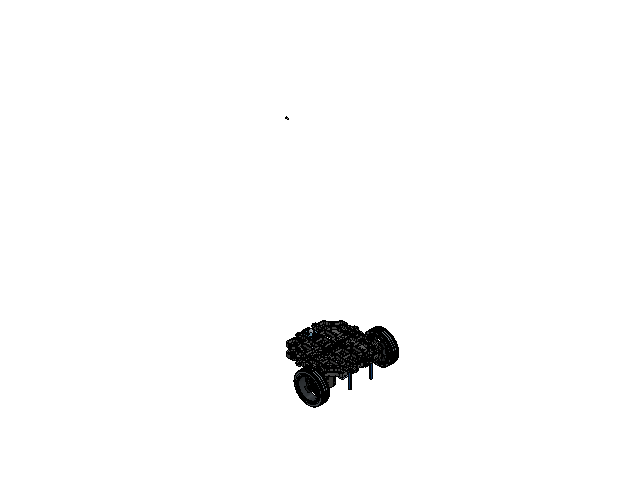
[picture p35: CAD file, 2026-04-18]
CAD/Turtlebot Assembly/First Layer.SLDASM
STEELBALL_3_8INCH
PR21_CASTER_CVR_3X5_REV6
P30_ISP_A001_3D x 2
PR16_A01_TIRE_2 x 2
M_PR07_A01_BRACKET_2 x 5
SUPPORT_HEX_M3_0XL35_FF x 4
Waffle Plate x 2
pan cross head_ks x 28
hexagon nut style 1 gradeab_ks x 4
LB-012 Battery

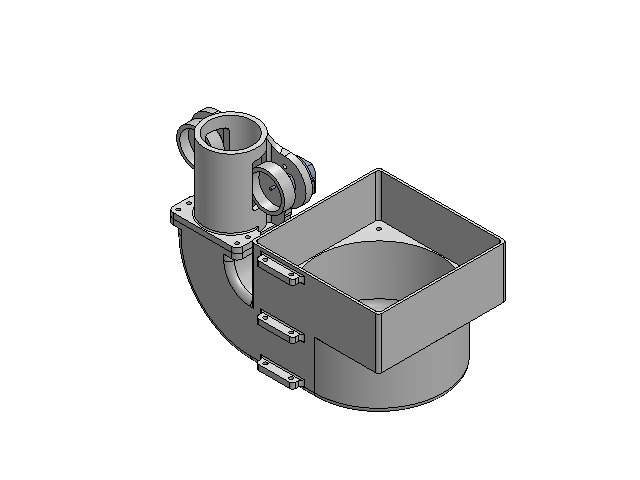
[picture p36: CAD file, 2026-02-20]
CAD/misc/reference/Launcher Assembly.SLDASM
Flywheel dummy x 2
Barrel guide
Carousell
Motor x 2
Motor Clamp x 2
Stepper Dummy

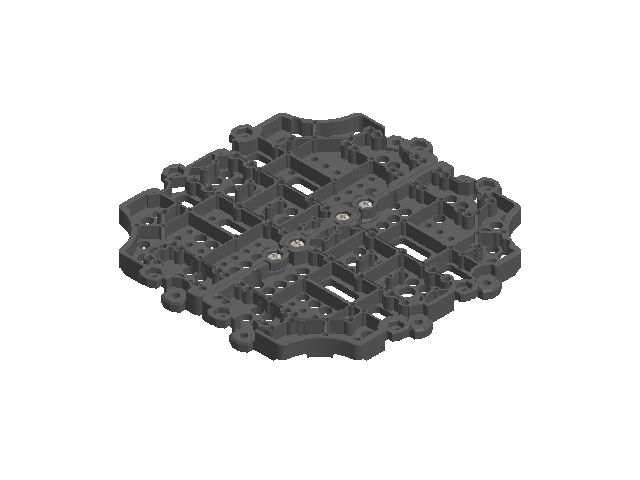
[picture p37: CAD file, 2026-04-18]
CAD/Turtlebot Assembly/Waffle Layer2.SLDASM
Waffle Plate x 2
pan cross head_ks x 4
hexagon nut style 1 gradeab_ks x 4

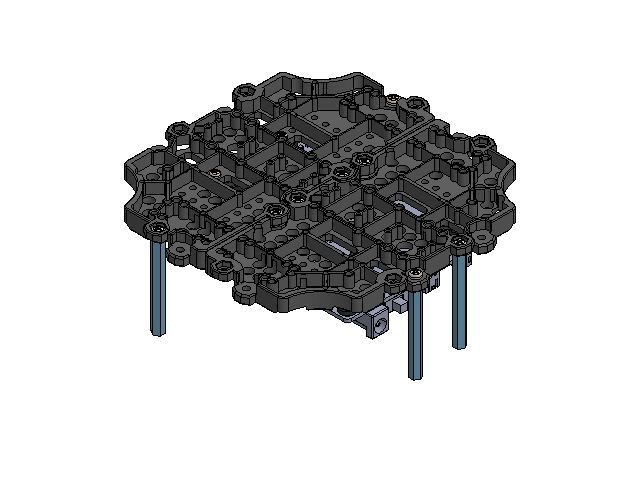
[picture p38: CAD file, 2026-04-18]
CAD/Turtlebot Assembly/Second Layer.SLDASM
Waffle Plate x 2
pan cross head_ks x 8
hexagon nut style 1 gradeab_ks x 8
PR30_IBB_01_3D x 4
OPENCR Dummy

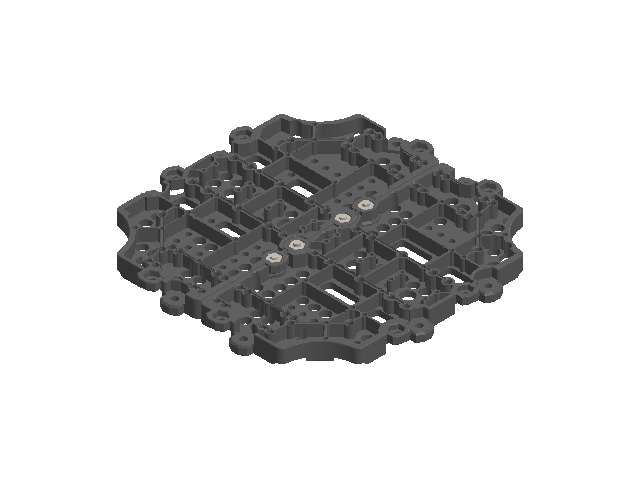
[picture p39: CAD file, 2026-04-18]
CAD/Turtlebot Assembly/Waffle Layer.SLDASM
Waffle Plate x 2
pan cross head_ks x 4
hexagon nut style 1 gradeab_ks x 4

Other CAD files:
CAD/misc/reference/launcher-main-body-fastener1.SLDPRT
CAD/misc/reference/rack.SLDASM
CAD/Turtlebot Assembly/Third Layer.SLDASM
CAD/misc/past-iterations/Turtlebot Assembly with payload.SLDASM
CAD/Turtlebot Assembly/530480810.SLDPRT
CAD/Turtlebot Assembly/BIC04_C01_PCB.SLDPRT
CAD/Turtlebot Assembly/Dynamixel Motor.SLDASM
CAD/Turtlebot Assembly/LB-012 Battery.SLDPRT
CAD/Turtlebot Assembly/LDS Dummy.SLDPRT
CAD/Turtlebot Assembly/MICRO_USB-3.SLDPRT
CAD/Turtlebot Assembly/MICRO_USB-4.SLDPRT
CAD/Turtlebot Assembly/MICRO_USB-5.SLDPRT
CAD/Turtlebot Assembly/MICRO_USB-6.SLDPRT
CAD/Turtlebot Assembly/MICRO_USB-8.SLDPRT
CAD/Turtlebot Assembly/MICRO_USB.SLDPRT
CAD/Turtlebot Assembly/M_PR07_A01_BRACKET_2.SLDPRT
CAD/Turtlebot Assembly/M_PR07_A01_SPACER_RIVET.SLDPRT
CAD/Turtlebot Assembly/OPENCR Dummy.SLDPRT
CAD/Turtlebot Assembly/OPENCR Dummy.STEP
CAD/Turtlebot Assembly/P30_ISP_A001_3D.SLDPRT
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

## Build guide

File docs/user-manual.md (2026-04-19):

## 🔗 Navigation

- [Home](index.md)
- [Requirements Specification](requirements-specification.md)
- [Concept of Operations](con-ops.md)
- [High Level Design](high-level-design.md)
- [Software Subsystem: Navigation and FSM](subsystem-nav-fsm.md)
- [Software Subsystem: ArUco Marker Detection](subsystem-software-aruco.md)
- [Mechanical Subsystem](subsystem-mechanical.md)
- [Electrical Subsystem](subsystem-electrical.md)
- [Interface Control Document](interface-control-document.md)
- [Software and Firmware Development](software-firmware-development.md)
- [Testing Documentation](testing-documentation.md)
- [User Manual](user-manual.md)
- [Areas for Improvement](improvements.md)
- [Appendix](appendix.md)

---

# User Manual

## End User Documentation
<div style="text-align: center; margin: 2rem 0;">
  <iframe 
    src="assets/END USER DOC.pdf" 
    width="80%" 
    height="600px" 
    style="border: none; box-shadow: 0 4px 16px rgba(0, 0, 0, 0.2);"
  >
  </iframe>
  <p>
    <a href="assets/END USER DOC.pdf" target="_blank" style="text-decoration: none;">
      📄 View PDF in a new tab
    </a>
  </p>
</div>

## Prerequisites

- ROS2 Humble
- TurtleBot3 workspace built successfully
- Required hardware connected for real-robot runs
- TurtleBot3 model set correctly for simulation (`burger`)
- All setup steps in `software-firmware-development.md` completed (dependencies, aliases, cleanup scripts, and launch helpers)

## Launch Sequences

### Gazebo simulation

Terminal 0 (before launch):

```bash
cleanup
```

Terminal 1:

```bash
export TURTLEBOT3_MODEL=burger
ros2 launch turtlebot3_gazebo turtlebot3_world.launch.py
```

Terminal 2:

```bash
ros2 launch auto_explore global_controller_bringup.py use_sim_time:=true \
	enable_fsm:=true enable_navigation:=true enable_markers:=true \
	enable_pose_publisher:=true enable_docking:=true enable_shooter:=true \
	shooter_enable_hardware:=false shooter_pigpiod_host:=<PI_IP_FROM_BOOT>
```

### Physical TurtleBot3

Terminal 1:

if rosbu & cleanup script is not set up:
```bash
ros2 launch turtlebot3_bringup robot.launch.py
```

else run:
```bash
rosbustop && rosbu
```

Terminal 2:

```bash
ros2 launch auto_explore global_controller_bringup.py use_sim_time:=false \
	enable_fsm:=true enable_navigation:=true enable_markers:=true \
	enable_pose_publisher:=true enable_docking:=true enable_shooter:=true \
	shooter_enable_hardware:=true shooter_pigpiod_host:=<PI_IP_FROM_BOOT>
```
If cleanup & start is set up:
Copy the Pi IP shown at boot and pass it to `shooter_pigpiod_host`.
```bash
cleanup && start <PI_IP_FROM_BOOT>
```
If shooter host or ultrasonic tuning arguments are required, launch `global_controller_bringup.py` directly, because those arguments are declared at the controller launch layer.

## Shutdown Procedure

- On the Raspberry Pi terminal running `rosbu`, press `Ctrl+C` to stop all bringup processes.
- On the laptop terminal running `start`, press `Ctrl+C` to stop all mission stack processes.
- Verify both terminals have returned to the shell prompt before the next run.

## Troubleshooting

Use the following live checks during runtime.

### 1) States

Command:

```bash
ros2 topic echo /states std_msgs/msg/String
```

Positive:
- State messages are publishing continuously and state transitions are sensible for mission phase.

Restart required:
- No `/states` output for more than 10 seconds.
- State machine is stuck indefinitely with no expected transition.

### 2) Map (frequency and echo)

Commands:

```bash
ros2 topic hz /map
ros2 topic echo /map --once
```

Positive:
- `/map` exists and publishes steadily.
- `echo --once` returns a valid OccupancyGrid message.

Restart required:
- `/map` topic missing.
- `/map` frequency remains zero for more than 10 seconds after startup delay.
- `echo --once` times out or returns no map data.

### 3) Scan

Commands:

```bash
ros2 topic hz /scan
ros2 topic echo /scan --once
```

Positive:
- `/scan` exists and updates continuously.

Restart required:
- `/scan` missing or no updates for more than 5 seconds.

### 4) TF

Commands:

```bash
ros2 topic hz /tf
ros2 topic echo /tf --once
```

Positive:
- `/tf` is active and broadcasting transforms.

Restart required:
- `/tf` is missing or not publishing.
- Navigation components report persistent transform/timeouts.

### 5) Topics Sanity

Command:

```bash
ros2 topic list | grep -E '^/states$|^/map$|^/scan$|^/tf$'
```

Positive:
- All required topics are present.

Restart required:
- One or more required topics are missing after startup completes.

### 6) RViz Not Pulling Up After Delay

Checks:

```bash
ros2 node list | grep rviz
```

Positive:
- RViz window appears after the configured startup delay.
- `rviz` node is visible in node list.

Restart required:
- RViz does not appear after delay and no `rviz` node is running.
- RViz repeatedly crashes on launch.

### Restart Decision Rule

Do a full system restart (stop `rosbu` and `start` with Ctrl+C, then relaunch) if any critical stream (`/states`, `/map`, `/scan`, `/tf`) fails the checks above and does not recover within 10 seconds.

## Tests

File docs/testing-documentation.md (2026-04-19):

## 🔗 Navigation

- [Home](index.md)
- [Requirements Specification](requirements-specification.md)
- [Concept of Operations](con-ops.md)
- [High Level Design](high-level-design.md)
- [Software Subsystem: Navigation and FSM](subsystem-nav-fsm.md)
- [Software Subsystem: ArUco Marker Detection](subsystem-software-aruco.md)
- [Mechanical Subsystem](subsystem-mechanical.md)
- [Electrical Subsystem](subsystem-electrical.md)
- [Interface Control Document](interface-control-document.md)
- [Software and Firmware Development](software-firmware-development.md)
- [Testing Documentation](testing-documentation.md)
- [User Manual](user-manual.md)
- [Areas for Improvement](improvements.md)
- [Appendix](appendix.md)

---

# Testing Documentation

## Navigation Testing Results (Physical Maze)

**Test Environment:** TurtleBot 3 Burger in physical maze  
**ROS 2 Distro:** Humble  
**Test Date Range:** 27/03 - 31/03/2026  

### Session S1 (27/03, 3:32 PM) – SLAM Dependency Issues

| Metric | Result |
|---|---|
| Outcome | **Fail** |
| Run Time | 0 min 0 s |
| Mapped Area | 0% |
| Collisions | 0 / 0 |

**Configuration:**
- `lookahead_distance:` 0.24 m
- `speed:` 0.18 m/s
- `expansion_size:` 3
- `target_error:` 0.15 m
- `robot_r:` 0.2 m

**Observations:**
- SLAM Toolbox had QoS dependency issues; could run in Gazebo but not with robot bringup
- Bot did not move as no SLAM map was created

**Evidence:**
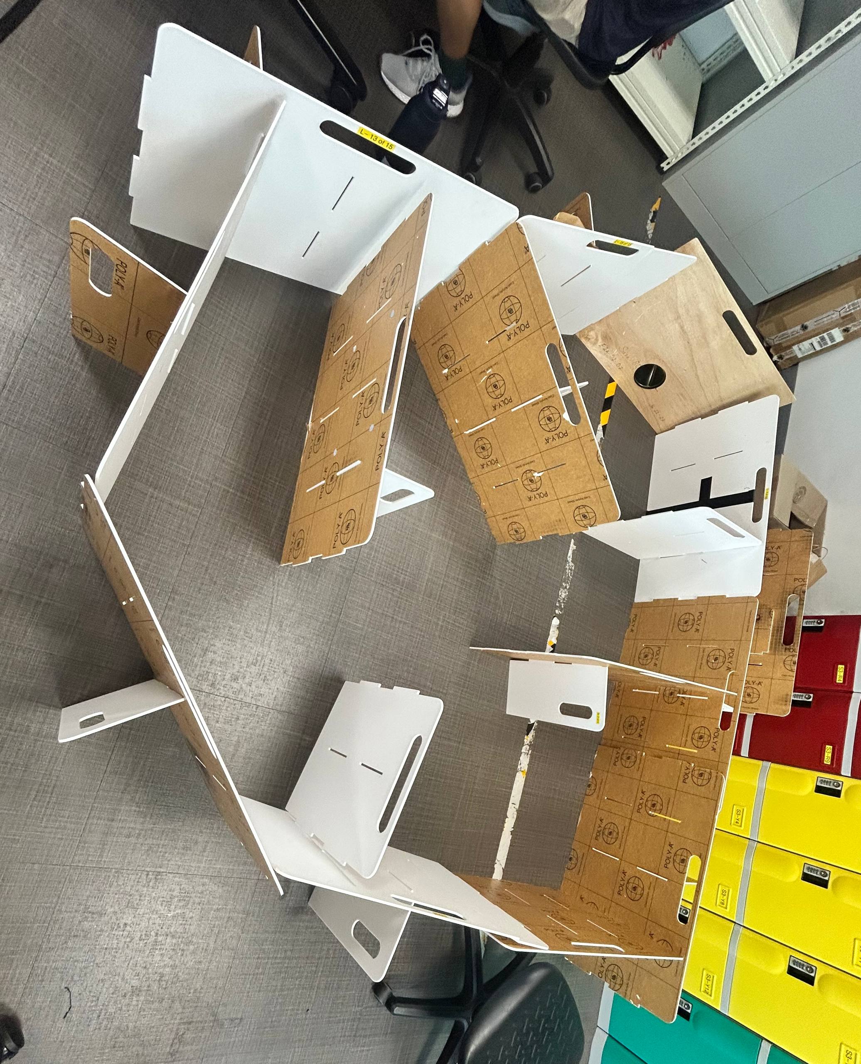
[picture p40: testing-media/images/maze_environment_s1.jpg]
Test Environment S1
- 

**Changes for Next Session:**
- Updated SLAM configuration in `/opt/ros/humble/share/slam_toolbox/config/mapper_params_online_async.yaml`

---

### Session S2 (27/03, 4:04 PM) – First Movement & Collision

| Metric | Result |
|---|---|
| Outcome | **Partial** |
| Run Time | 0 min 26 s |
| Mapped Area | ~5% |
| Collisions | 1 |

**Configuration:**
- `lookahead_distance:` 0.24 m
- `speed:` 0.18 m/s
- `expansion_size:` 3
- `target_error:` 0.15 m
- `robot_r:` 0.2 m
- Updated SLAM mapper parameters: `map_update_interval: 1.0`, `min_laser_range: 0.12`, `max_laser_range: 3.5`, `minimum_travel_distance: 0.2`

**Observations:**
- Bot collided with wall after first turn
- Map generated but SLAM latency caused delayed obstacle awareness
- Robot did not avoid walls/obstacles effectively

**Evidence:**
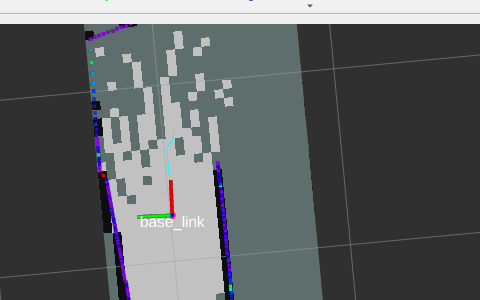
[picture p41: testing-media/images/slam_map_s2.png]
SLAM Map Generated S2
- 
- Video: [Collision Incident S2](../testing-media/videos/collision_s2.mp4)

**Changes for Next Session:**
- Reduce speed from 0.18 m/s to 0.09 m/s to counteract SLAM latency and enable smoother maneuvering

---

### Session S3 (31/03, 3:27 PM) – Speed Reduction & Success

| Metric | Result |
|---|---|
| Outcome | **Success** ✓ |
| Run Time | 0 min 53 s |
| Mapped Area | 100% |
| Collisions | 0 / 0 |

**Configuration:**
- `lookahead_distance:` 0.24 m
- `speed:` 0.09 m/s *(reduced from 0.18)*
- `expansion_size:` 3
- `target_error:` 0.15 m
- `robot_r:` 0.2 m

**Procedure:**
- Max speed reduced from 0.18 m/s to 0.09 m/s to accommodate SLAM processing latency
- Robot allowed to explore maze autonomously without intervention

**Observations:**
- Robot successfully navigated entire maze without collision
- Reduced speed (0.09 m/s) provided sufficient time for SLAM to update map before path planning decisions
- Smooth exploration pattern with effective frontier detection
- No oscillation or navigation errors observed
- Complete map coverage achieved in under 1 minute
- Robot correctly transitioned to completion state upon 100% map coverage

**Evidence:**
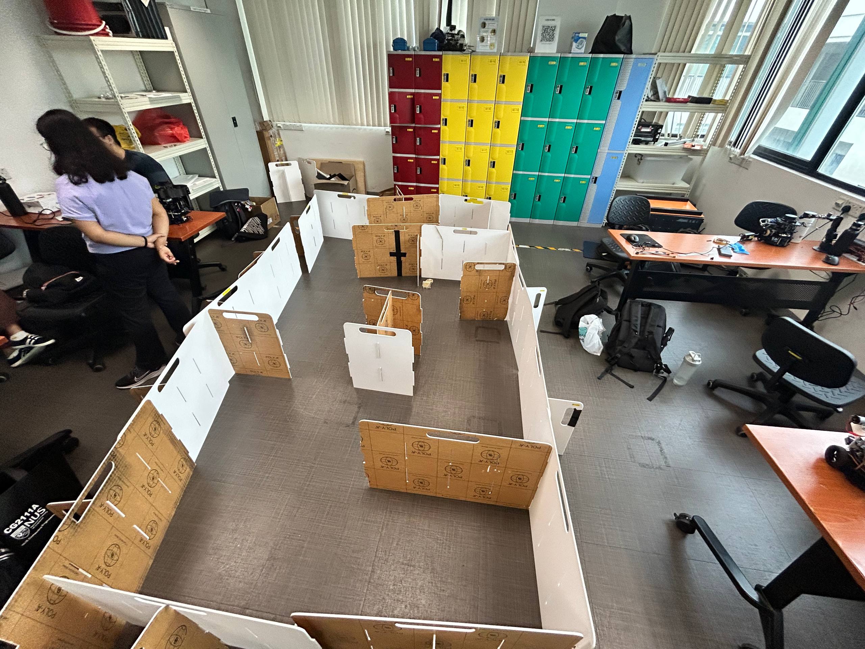
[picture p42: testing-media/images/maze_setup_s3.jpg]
Test Setup S3
- 
- Video: [Run Video S3](../testing-media/videos/exploration_run_s3.mp4)
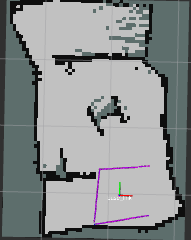
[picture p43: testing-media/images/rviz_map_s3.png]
RViz Map S3
- 

**Key Findings:**
- **Speed optimization is critical:** Reducing speed from 0.18 m/s to 0.09 m/s eliminated collisions
- **SLAM latency resolved:** Slower movement rate allowed map updates to propagate before path planning
- **Frontier algorithm effective:** Algorithm successfully identified and navigated to unexplored regions
- **Completion criteria met:** 100% map coverage achieved with zero collisions in 53 seconds

### 5) Marker detection only

```bash
ros2 launch auto_explore global_controller_bringup.py use_sim_time:=true \
	enable_fsm:=false enable_navigation:=false enable_markers:=true \
	enable_pose_publisher:=true enable_docking:=false enable_shooter:=false
```

Check:

```bash
ros2 topic echo /aruco/debug
ros2 topic echo /tf
ros2 topic echo /marker_detected
```

Expected: the ArUco detection node should publish heartbeat/debug output on `/aruco/debug`, publish `true` on `/marker_detected` when a marker is visible, and publish marker pose transforms on `/tf` with frame names of the form `aruco_marker_<id>`.

## ArUco Marker Detection Testing Results (Physical Robot)

**Test Environment:** TurtleBot 3 Burger with Raspberry Pi camera and printed ArUco marker  
**ROS 2 Distro:** Humble  
**Test Date Range:** 02/04/2026  

### Session A1 (02/04, 3:07 PM) – Heartbeat, Detection State, and Pose Publishing Validation

| Metric | Result |
|---|---|
| Outcome | **Success** ✓ |
| Run Time | 1 min 12 s |
| Marker IDs Detected | 1 |
| Detection State | **`true`** |

**Configuration:**
- `image_topic:` `/camera/image_raw`
- `camera_info_topic:` `/camera/camera_info`
- `camera_frame:` `camera_optical_frame`
- `marker_size_m:` 0.049 m
- `dictionary:` `DICT_4X4_250`
- Marker placement distance: ~0.35 m to 0.60 m from camera

**Procedure:**
- Launched the ArUco pose streamer independently with marker detection enabled
- Checked `/aruco/debug` to confirm heartbeat and debug JSON output
- Checked `/marker_detected` to confirm marker visibility state
- Checked `/tf` to confirm pose transform publishing for the detected marker

**Observations:**
- The subsystem worked correctly on the first physical test run without requiring code changes
- `/aruco/debug` published both heartbeat information and marker debug data as expected
- `/marker_detected` correctly changed to `true` when the marker entered the camera view
- `/tf` published the marker pose using parent frame `camera_optical_frame` and child frame `aruco_marker_<id>`
- The published pose output was stable enough to be used directly by the downstream docking subsystem

**Evidence:**
- Setup Image: [ArUco Detection Validation](../testing-media/images/Aruco_Test_d1.jpg)
- Screenshot: [/marker_detected output](../testing-media/images/Aruco_marker_detected.png)
- Screenshot: [/tf output](../testing-media/images/Aruco_tf.png)
- Screenshot: [/arUco/debug output](../testing-media/images/Aruco_aruco_debug.png)

**Key Findings:**
- **Heartbeat output worked correctly:** the node continuously indicated that the subsystem was running
- **Detection state publishing worked correctly:** marker visibility was reflected reliably on `/marker_detected`
- **Pose publishing worked correctly:** TF transforms were published in the expected frame structure for downstream use
- **Subsystem was ready for integration:** marker output was immediately usable by the docking controller

### 6) Docking controller only

```bash
ros2 launch auto_explore global_controller_bringup.py use_sim_time:=true \
	enable_fsm:=false enable_navigation:=false enable_markers:=false \
	enable_docking:=true enable_shooter:=false
```

Check:

```bash
ros2 topic info /cmd_vel_docking
ros2 topic info /dock_done
ros2 topic echo /docking_state
```

Expected: docking topics are present, the controller is alive, and the docking state machine publishes valid transitions during a run.

## Docking Testing Results (Physical Robot)

**Test Environment:** TurtleBot 3 Burger with camera-based ArUco docking target  
**ROS 2 Distro:** Humble  
**Test Date Range:** 04/04 - 08/04/2026  

### Session D1 (04/04, 5:10 PM) – Initial Path-Based Docking Attempt

| Metric | Result |
|---|---|
| Outcome | **Fail** |
| Run Time | 0 min 18 s |
| Dock Complete | No |
| Marker Lock | Intermittent |

**Configuration:**
- `lookahead_distance:` 0.24 m
- `cruise_speed:` 0.12 m/s
- `target_error:` 0.10 m
- `robot_safety_radius:` 0.20 m
- `final_align_trigger_margin:` 0.50 m
- `max_path_ang_speed:` 0.70 rad/s
- `max_final_ang_speed:` 0.15 rad/s
- Marker set tested: `0, 10, 21, 30, 31, 32`

**Procedure:**
- Ran the earlier docking controller version that combined A* planning, B-spline smoothing, path following, search rotation, and TF-based final alignment
- Tested on the physical robot with real `/tf`, `/odom`, `/scan`, and `/map` inputs

**Observations:**
- Controller logic performed correctly in Gazebo but was not reliable on the real robot
- In physical testing, the robot either remained stationary or just rotated side to side during docking attempts
- Marker-triggered phase transitions occurred, but the global behaviour was not stable enough for successful docking
- This suggested a gap between simulated frame assumptions and real-world robot behaviour

**Evidence:**
- Video: [Physical Docking Failure D1](../testing-media/videos/docking_failure_d1.mp4)

**Changes for Next Session:**
- Replaced the path-heavy docking approach with a simpler state-based controller using direct pose feedback from ArUco and a LiDAR verification check in the final approach stage

---

### Session D2 (06/04, 4:42 PM) – Pose-Based Docking Controller Success

| Metric | Result |
|---|---|
| Outcome | **Success** ✓ |
| Run Time | 0 min 21 s |
| Dock Complete | Yes |
| Marker Lock | Stable |

**Configuration:**
- `forward_speed:` 0.08 m/s
- `turn_kp:` 1.8
- `max_ang_speed:` 0.25 rad/s
- `turn_tolerance:` 2.0 deg
- `mid_tz_threshold:` 0.30 m
- `final_tz_threshold:` 0.10 m
- `tx_align_tolerance:` 0.01 m
- `tx_final_align_tolerance:` 0.05 m
- Added docking fail-safes: `marker_invisible_timeout_sec: 30.0`, `state_timeout_sec: 45.0`

**Procedure:**
- Re-tested using the revised docking controller based on a staged state machine:
  `SEARCH -> APPROACH_1 -> TURN_SIDE / DRIVE_SIDE -> TURN_FACE_MARKER -> FINAL_APPROACH -> DONE`
- Used ArUco pose data for alignment and LiDAR as a final safety confirmation near the docking threshold

**Observations:**
- Robot successfully rotated to face the marker, approached it, corrected its heading, and completed final docking
- State transitions were consistent and easier to debug than in the earlier controller version
- The simplified approach reduced incorrect path behaviour seen in D1
- LiDAR provided a useful final cross-check before declaring docking complete
- `/dock_done` published the expected completion signal at the end of the sequence

**Evidence:**
- Video: [Docking Run Video 1 D2](../testing-media/videos/docking_success_d2_1.mp4)
- Video: [Docking Run Video 2 D2](../testing-media/videos/docking_success_d2_2.mp4)

**Key Findings:**
- **Simpler control logic was more robust:** direct pose-based alignment outperformed the earlier planner-heavy implementation on hardware
- **State-machine visibility improved debugging:** the explicit docking states made it easier to identify where errors occurred
- **Final sensing redundancy helped:** LiDAR confirmation reduced the chance of false completion near the target
- **Physical docking criteria were met:** the robot completed docking reliably within the acceptable stopping distance

---

### 7) Shooter controller only

Simulation-safe launch:

```bash
ros2 launch auto_explore global_controller_bringup.py use_sim_time:=true \
	enable_fsm:=false enable_navigation:=false enable_markers:=false \
	enable_docking:=false enable_shooter:=true shooter_enable_hardware:=false
```

Trigger shooter modes:

```bash
ros2 topic pub --once /shoot_type std_msgs/String "data: static"
ros2 topic pub --once /shoot_type std_msgs/String "data: dynamic"
```

Expected: shooter starts without GPIO access errors.

## Integration Tests

### Navigation + Mission Control

**Test Status:** In progress (pending S3 results)  

**Test Objective:** Verify frontier-based exploration integrates correctly with FSM state machine.

**Procedure:**
```bash
ros2 launch auto_explore global_controller_bringup.py use_sim_time:=false \
	enable_fsm:=true enable_navigation:=true enable_markers:=false \
	enable_docking:=false enable_shooter:=false
```

**Evidence Placeholder:**
- Video: [FSM State Transitions](../testing-media/videos/fsm_state_transitions_nav.mp4)
- Navigation Integrated Output

### Marker Detection + Mission Control

**Test Objective:** Verify that FSM-controlled mission flow can transition into marker-aware behavior once a marker becomes visible.

**Procedure:**
```bash
ros2 launch auto_explore global_controller_bringup.py use_sim_time:=false \
	enable_fsm:=true enable_navigation:=false enable_markers:=true \
	enable_pose_publisher:=true enable_docking:=false enable_shooter:=false
```

**Expected Behavior:**
- FSM remains alive while marker topics are active
- Marker detection continues publishing independently of navigation
- Visible marker data is available for downstream docking logic

**Evidence Placeholder:**
- Video: [FSM + Marker Detection](../testing-media/videos/fsm_marker_integration.mp4)

### Full Bringup with Toggles Enabled

**Test Objective:** Verify that navigation, FSM, marker detection, and docking interfaces can coexist without launch conflicts.

**Procedure:**
```bash
ros2 launch auto_explore global_bringup.py \
	use_sim_time:=false enable_slam:=false enable_rviz:=false \
	enable_fsm:=true enable_navigation:=true enable_markers:=true \
	enable_pose_publisher:=true enable_docking:=true enable_shooter:=false
```

**Expected Behavior:**
- All required nodes launch without runtime exceptions
- Core topics remain available simultaneously
- Marker and docking interfaces do not break navigation bringup

**Evidence Placeholder:**
- Screenshot: `ros2 node list`
- Screenshot: `ros2 topic list`

## End-to-End Mission Tests

### Full smoke test (simulation)

```bash
ros2 launch auto_explore global_bringup.py \
	use_sim_time:=true enable_slam:=true enable_rviz:=false \
	enable_fsm:=true enable_navigation:=true enable_markers:=true \
	enable_pose_publisher:=true enable_docking:=false enable_shooter:=false
```

Check:

```bash
ros2 topic list | grep -E '^/states$|^/aruco/debug$|^/cmd_vel$|^/map$|^/odom$'
```

Expected: critical topics are present and active.

### Full stack test (real robot)

Run robot bringup and launch integrated mission stack with real-time settings and hardware flags.

## Acceptance Criteria

- Required topics appear.
- Nodes launch without runtime exceptions.
- Mission states transition as expected.

## Navigation Subsystem Summary

**Subsystem Owner:** Navigation / Autonomous Exploration  
**Test Period:** 27/03/2026 – 31/03/2026  
**Physical Environment:** Maze with walls and tight passages  

### Test Results Summary

| Session | Date | Outcome | Key Issue | Speed | Mapped % | Collisions |
|---|---|---|---|---|---|---|
| S1 | 27/03 | Fail | SLAM config error | 0.18 | 0% | 0 |
| S2 | 27/03 | Partial | Wall collision | 0.18 | 5% | 1 |
| S3 | 31/03 | **Success** | Speed optimization | 0.09 | **100%** | **0** |

### Key Learnings

1. **SLAM Latency:** Critical factor affecting real-time obstacle avoidance
2. **Speed Sensitivity:** Higher speeds (0.18 m/s) exceeded SLAM update rate; slower speeds (0.09 m/s) recommended
3. **Mapper Parameters:** Fine-tuning `map_update_interval`, `minimum_travel_distance`, and laser range bounds essential for responsiveness
4. **Frontier Algorithm:** Core algorithm functional; primary issue is external timing constraints rather than algorithmic failure

### Recommendations

- S3 parameters (speed: 0.09 m/s) are recommended for operational deployment
- Current configuration successfully meets acceptance criteria: 100% map coverage with 0 collisions
- Further optimization may focus on reducing exploration time without sacrificing safety
- Consider implementing dynamic speed scaling based on map confidence for future enhancements

## ArUco Marker Detection Subsystem Summary

**Subsystem Owner:** Perception / Marker Detection  
**Test Period:** 02/04/2026  
**Physical Environment:** Indoor bench and floor-level marker visibility tests  

### Test Results Summary

| Session | Date | Outcome | Key Issue | TF Output | Detection State |
|---|---|---|---|---|---|
| A1 | 02/04 | **Success** | First-run validation | **Published** | **`true`** |

### Key Learnings

1. **Heartbeat output was verified:** the subsystem continuously indicated that the node was running
2. **Marker visibility publishing was correct:** `/marker_detected` reflected marker presence correctly
3. **Pose publishing was successful:** TF transforms were published correctly for the visible marker
4. **Subsystem worked first shot:** no code changes were required before integration with docking

### Recommendations

- Keep the same camera topic and marker size configuration for integration testing
- Record topic screenshots for `/aruco/debug`, `/tf`, and `/marker_detected` during demonstrations
- Maintain a clear frontal view of the marker for best pose stability

## Docking Subsystem Summary

**Subsystem Owner:** Docking / Final Alignment Control  
**Test Period:** 04/04/2026 – 08/04/2026  
**Physical Environment:** Indoor floor docking tests using ArUco-based visual docking target  

### Test Results Summary

| Session | Date | Outcome | Key Issue | Dock Complete | Notes |
|---|---|---|---|---|---|
| D1 | 04/04 | Fail | Planner-heavy controller unstable on hardware | No | Worked in Gazebo, not on robot |
| D2 | 06/04 | **Success** | Simplified control logic | **Yes** | Full docking completed |

### Key Learnings

1. **Hardware realism matters:** a controller that appears correct in Gazebo may still fail on the physical platform
2. **Simpler docking logic was more effective:** direct pose-based control using ArUco measurements was more reliable than the earlier path-planning approach
3. **State-machine structure improved reliability:** explicit state transitions made debugging, testing, and recovery much easier
4. **Sensor redundancy improved confidence:** ArUco pose guidance combined with LiDAR confirmation produced a more dependable final approach

### Recommendations

- Use the revised pose-based controller as the baseline docking implementation
- Keep the successful D2 parameter set for demonstrations and integration testing
- Preserve watchdog-based abort logic in all future docking revisions
- During demonstrations, record both the robot motion and topic output for stronger validation evidence

## Known Test Gaps

- Long-duration exploration runs (>5 min) not yet validated
- Integration with full mission FSM (marker detection + docking) pending
- Hardware-specific validation remains dependent on available robot access

## Evidence and Results

- Suggested evidence artifacts:
	- topic snapshots (`ros2 topic list`, `ros2 topic hz`)
	- node lists (`ros2 node list`)
	- launch logs from `~/.ros/log/`
	- RViz screenshots or short run recordings
   
## Testing Documentation: Electrical Subsystem

## Test Strategy

- **Unit Validation**: Confirm individual component functionality (Servos, Ultrasonic) before full integration.
- **Signal Integrity**: Verify logic level compatibility between the Raspberry Pi and actuators.
- **Power Reliability**: Ensure the power distribution network handles currents without system brownouts.
- **Mission Endurance**: Validate the 25-minute operational requirement under real-world conditions.

## Subsystem Unit Tests

### 1) MG90S PWM Logic Level Test

**Objective**: Verify MG90S response to different control voltages.

**Procedure**: Initially connected MG90S directly to RPi GPIO 13. Following failure, integrated BOB-11978 Level Shifter. Verified signal using a Digital Multimeter.

**Observations**:
- At 3.3V PWM: The servo remained still and failed to actuate.
- At 5.0V PWM (via BOB-11978): Servo responded correctly to PWM commands.

**Result**: ✅ Success (Requires Level Shifter)

---

### 2) HC-SR04 Voltage Divider Safety

**Objective**: Protect RPi GPIO from 5V Echo signals.

**Procedure**: Implemented 1kΩ-2kΩ voltage divider. Measured output voltage with a Digital Multimeter during active ranging.

- **Expected**: Signal stepped down to ~3.3V.
- **Actual**: ~3.33V measured at GPIO 24.

**Result**: ✅ Success

---

### 3) Startup Stability Test

**Objective**: Ensure "No unintended actuation of servos or drive motors on startup" (Req 2.4).

**Procedure**: Monitored SG90 and MG90S positions during OpenCR and RPi boot cycles.

**Observations**: Both servos successfully initialized to stop/closed pulse widths without jitter or movement before commands were issued.

**Result**: ✅ Success

---

### 4) Full Endurance Run (Physical)

**Test Environment:** NUS IDP Studio 2  
**Test Date:** 13/04/2026 – 16/04/2026  
**Robot State:** Integrated launcher mechanism and navigation stack active.

| Metric | Target | Result |
|---|---|---|
| Outcome | Success | Mission Completed |
| Run Time | 25 min 0 s | 25 min 0 s |
| Battery Voltage | >11 V | >11 V (Alarm stayed silent) |

**Observations**:
- Robot completed the full duration without triggering the OpenCR low-voltage alarm (threshold: 11V).
- Confirmed battery capacity remains sufficient for the 25-minute requirement, consistent with the predicted worst-case runtime of 54.9 minutes.
- No system brownouts or reboots occurred during concurrent movement and servo actuation

## Spring-loaded Launcher Subsystem Summary

**Subsystem Owner:** Mechanical / Launcher Integration  
**Test Period:** Iterative design versions v1-v4, followed by final validation  
**Physical Environment:** Bench and integrated robot launcher tests

### Technical Performance Measures (TPM)

| TPM | Requirement | Result |
|---|---|---|
| TPM1 | Launch vertical range equal to or further than the set docking tolerance of 15 cm | Met in final validation |
| TPM2 | Vertical drop-off within the height difference of the launch point and the receptacle | Met in final validation |
| TPM3 | Timing sequence success rate for sequential ball launches | Met in final validation |

### Measures of Effectiveness (MOE)

| MOE | Requirement | Result |
|---|---|---|
| MOE1 | All launches deliver balls successfully into the respective delivery receptacle following the correct timing sequence | Met in final validation |
| MOE2 | Zero mechanical jams during runs | Met in final validation |

### Test Results Summary

| Version | Key Issue | Fix Applied | Outcome |
|---|---|---|---|
| V1 | Rack and pinion tolerance too tight; pusher taller than required | Cut wall to fit pinion; reduced pusher height | Partial |
| V2 | Wiring and servo integration not serviceable; launcher difficult to service; pusher oversized; rack interference near pinion wall | Added wire holes and servo gate mount; made launcher detachable from hex mounts; reduced pusher size and height; removed wall for pinion fit | Improvement |
| V3 | Ball did not drop nicely into launcher; wall friction reduced launch distance; rack needed more pullback; gear slipping under load | Moved stop further up and increased gear teeth; removed launcher walls and sanded walls; increased gear teeth; reduced gear distance by lowering servo height | Improvement |
| V4 | Ball could fall out laterally; launcher flexed under load; servo screw fit loose; residual gear distance issue; launch angle insufficient | Added side wall; increased wall thickness; reduced servo screw hole diameter; reduced gear distance more; moved bottom hex mount hole lower to tilt launcher; added servo cover | Success |
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

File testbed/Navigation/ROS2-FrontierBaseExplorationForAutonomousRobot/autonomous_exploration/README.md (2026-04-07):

# Autonomous Exploration – TurtleBot

This package implements a frontier‑based exploration controller for a TurtleBot using ROS 2.  
Configuration is stored in [autonomous_exploration/config/params.yaml](autonomous_exploration/config/params.yaml).

---

## 1. Parameters

Current defaults in [autonomous_exploration/config/params.yaml](autonomous_exploration/config/params.yaml):

```yaml
lookahead_distance : 0.24 # lookahead distance
speed             : 0.18  # maximum speed
expansion_size    : 3     # wall expansion coefficient
target_error      : 0.15  # target error margin
robot_r           : 0.2   # robot distance for local safety
```

| Parameter | Meaning (layman) | Typical tuning |
|---|---|---|
| `lookahead_distance` | How far along the path the robot “aims” when steering. | Smaller → cautious, sharp turns. Larger → smoother, may cut corners / get closer to walls. |
| `speed` | Max forward speed (m/s). | Start low (0.10–0.18). Increase as confidence grows. |
| `expansion_size` | How much obstacles are “fattened” in the costmap (in grid cells). | Larger → keeps away from walls, can block narrow gaps. Smaller → fits tight gaps, higher collision risk. |
| `target_error` | Distance threshold (m) to consider a target/frontier reached. | Too small → oscillates at goals. Too large → may stop short and map less. |
| `robot_r` | Safety radius used in local obstacle checks around the robot (m). | Increase if it feels too close to obstacles; decrease if it is too conservative in narrow passages. |

To change behaviour, edit the YAML file, rebuild, and re‑run.

---

## 2. Build & Run

From the workspace root:

```bash
cd /home/jw/Desktop/CDE2310/CDE2310_G10_2526
colcon build
source install/setup.bash
```

Then run the exploration node:

```bash
ros2 run autonomous_exploration control
```

Prerequisites (already running on robot / network):

- TurtleBot bringup (publishing `/scan`, `/odom`, `/tf`).
- SLAM node (publishing `/map`, e.g. slam_toolbox).

---

## 3. Typical Test Procedure (Physical Maze)

1. Start robot bringup (example, adapt to your model):

   ```bash
   ros2 launch turtlebot3_bringup robot.launch.py
   ```

2. Start SLAM:

   ```bash
   ros2 launch slam_toolbox online_async_launch.py
   ```

3. Check topics:

   ```bash
   ros2 topic list
   ```

   Expect at least: `/scan`, `/odom`, `/map`, `/cmd_vel`.

4. Start RViz2 and visualize:

   ```bash
   rviz2
   ```

   - Fixed frame: `map`
   - Displays: `/map`, `/scan`, `RobotModel`/TF.

5. Run exploration:

   ```bash
   ros2 run autonomous_exploration control
   ```

Have an emergency stop (Ctrl+C + physical stop button).

---

## 4. Per‑Session Testing & Validation 

- **Goal / success criteria: 100% Map Completion & 0 Collisions**  

**100% Map Completion Example**
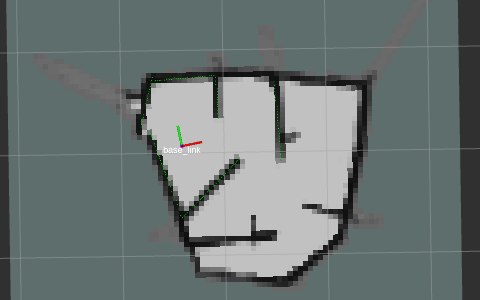
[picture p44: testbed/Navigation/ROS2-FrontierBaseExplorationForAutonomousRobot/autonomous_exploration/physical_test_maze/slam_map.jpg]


## Session Info

- **Session ID / Name:** `S1`
- **Date & Time:** `27/03 3:32PM`
- **Maze / Environment:** 
- **Robot & ROS 2 distro:** `Humble`

### Setup

- **params.yaml (key values):**
  - `lookahead_distance:` `0.24` m
  - `speed:` `0.18` m/s
  - `expansion_size:` `3`
  - `target_error:` `0.15` m
  - `robot_r:` `0.2` m

### Procedure

Short bullet list of what was done (commands + steps):

- `Baseline testing of algorithm with params unchanged`

### Results

- **Outcome:** success / partial / **fail**
- **Run time:** `0` min `0` s
- **Mapped area (rough %):** `0 %`
- **Collisions / near‑collisions:** `________ / ________`

### Observations

Write 3–5 short points:

- `Slam Toolbox had QOS dependency issues, could run in gazebo but not with rosbu`
- `Bot did not move as no SLAM map was created`

### Changes for Next Session

- Parameter tweaks (before → after):
  - `speed:` `________ → ________`
  - `expansion_size:` `________ → ________`
  - other: `__________________________________________`
- Code or setup changes:
  - `in /opt/ros/humble/share/slam_toolbox/config directory, update the parameters in the mapper_params_online_async.yaml file to improve SLAM efficiency`

### Quick Summary

- What worked well: `________________________________________________`
- Main problem left: `Slam Map not created`

## Session Info

- **Session ID / Name:** `S2`
- **Date & Time:** `27/03 4:04PM`
- **Maze / Environment:** 
- **Robot & ROS 2 distro:** `Humble`

### Setup

- **params.yaml (key values):**
  - `lookahead_distance:` `0.24` m
  - `speed:` `0.18` m/s
  - `expansion_size:` `3`
  - `target_error:` `0.15` m
  - `robot_r:` `0.2` m

### Procedure

Short bullet list of what was done (commands + steps):

- `Below parameters changed in the mapper_params_online_async.yaml file:

slam_toolbox:
    ros__parameters:
    
    solver_plugin: solver_plugins::CeresSolver
    ceres_linear_solver: SPARSE_NORMAL_CHOLESKY
    ceres_preconditioner: SCHUR_JACOBI
    ceres_trust_strategy: LEVENBERG_MARQUARDT
    ceres_dogleg_type: TRADITIONAL_DOGLEG
    ceres_loss_function: None

    odom_frame: odom
    map_frame: map
    base_frame: base_footprint
    scan_topic: /scan
    use_map_saver: true
    mode: mapping

    debug_logging: false
    throttle_scans: 1
    transform_publish_period: 0.02
    map_update_interval: 1.0        # was 5.0 - faster map updates
    resolution: 0.05
    min_laser_range: 0.12           # was 0.0 - match LiDAR's (LDS-02) actual min range
    max_laser_range: 3.5            # was 20.0 - match LiDAR's (LDS-02) actual max range
    minimum_time_interval: 0.2      # was 0.5 - process scans more frequently
    transform_timeout: 0.2
    tf_buffer_duration: 30.
    stack_size_to_use: 40000000
    enable_interactive_mode: true

    use_scan_matching: true
    use_scan_barycenter: true
    minimum_travel_distance: 0.2    # was 0.5 - update after smaller movements
    minimum_travel_heading: 0.2     # was 0.5 - update after smaller rotations
    scan_buffer_size: 10
    scan_buffer_maximum_scan_distance: 3.5  # match max_laser_range
    link_match_minimum_response_fine: 0.1  
    link_scan_maximum_distance: 1.5
    loop_search_maximum_distance: 3.0
    do_loop_closing: true 
    loop_match_minimum_chain_size: 10           
    loop_match_maximum_variance_coarse: 3.0  
    loop_match_minimum_response_coarse: 0.35    
    loop_match_minimum_response_fine: 0.45

    correlation_search_space_dimension: 0.5
    correlation_search_space_resolution: 0.01
    correlation_search_space_smear_deviation: 0.1 

    loop_search_space_dimension: 8.0
    loop_search_space_resolution: 0.05
    loop_search_space_smear_deviation: 0.03

    distance_variance_penalty: 0.5      
    angle_variance_penalty: 1.0    
    fine_search_angle_offset: 0.00349     
    coarse_search_angle_offset: 0.349   
    coarse_angle_resolution: 0.0349        
    minimum_angle_penalty: 0.9
    minimum_distance_penalty: 0.5
    use_response_expansion: true
    min_pass_through: 2
    occupancy_threshold: 0.1`

### Results

- **Outcome:** success / **partial** / fail
- **Run time:** `0` min `15` s
- **Mapped area (rough %):** `5 %`
- **Collisions / near‑collisions:** `1 / ________`

### Observations

Write 3–5 short points:

- `Bot collided with wall after first turn`

### Changes for Next Session

- Parameter tweaks (before → after):
  - `speed:` `________ → ________`
  - `expansion_size:` `________ → ________`
  - other: `__________________________________________`
- Code or setup changes:
  - `Decrease speed to counteract SLAM latency issues, as well as smoother maneuvering`

### Quick Summary

- What worked well: `Map is generated and robot moves`
- Main problem left: `Robot does not avoid walls/obstacles effectively + SLAM map is generated slowly`

## Session Info

- **Session ID / Name:** `S3`
- **Date & Time:** `31/03 3:27PM`
- **Maze / Environment:** 
- **Robot & ROS 2 distro:** `Humble`

### Setup

- **params.yaml (key values):**
  - `lookahead_distance:` `0.24` m
  - `speed:` `0.09` m/s
  - `expansion_size:` `3`
  - `target_error:` `0.15` m
  - `robot_r:` `0.2` m

### Procedure

Short bullet list of what was done (commands + steps):

- `max speed reduced from 0.18 m/s to 0.09 m/s`

### Results

- **Outcome:** success / partial / fail
- **Run time:** `` min `` s
- **Mapped area (rough %):** ` %`
- **Collisions / near‑collisions:** ` / ________`

### Observations

Write 3–5 short points:

- `

### Changes for Next Session

- Parameter tweaks (before → after):
  - `speed:` `________ → ________`
  - `expansion_size:` `________ → ________`
  - other: `__________________________________________`
- Code or setup changes:
  - `

### Quick Summary

- What worked well: ``
- Main problem left: ``

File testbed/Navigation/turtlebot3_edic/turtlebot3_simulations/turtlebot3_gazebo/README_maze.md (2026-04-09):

# TurtleBot3 Simple Maze World

This world file creates a simple maze environment for basic navigation, SLAM, and autonomous driving testing with the TurtleBot3 platform.

## Overview

The simple maze world provides a clean testing environment for:

### Key Features

1. **🟢 Start Zone**: Green platform at (-5, -3) where the robot begins
2. **🧱 Maze Layout**: Multiple internal walls creating navigation challenges
3. **🏗️ Outer Boundaries**: Perimeter walls defining the maze area
4. **💡 Proper Lighting**: Multiple light sources for realistic conditions

### World Layout

```
    +---+---+---+---+---+---+---+---+---+---+---+---+
    |       |                           |           |
    |       |                           |     |     |
    |       |                           |     |     |
    |   +---+                           +-----+     |
    |       |                                       |
    |   +---+---+   +---+                          |
    |           |   |                               |
    |   |       |   |       +---+                  |
    |   |       |           |                      |
    | [S]       |           |           +---+      |
    |           |           |                      |
    +---+---+---+---+---+---+---+---+---+---+---+---+

Legend:
[S] = Start Zone (Green Platform)
+---+ = Walls and obstacles
```

## Usage Instructions

### 1. Launch the Simple Maze World

```bash
# Set TurtleBot3 model
export TURTLEBOT3_MODEL=burger

# Launch the simple maze simulation
ros2 launch turtlebot3_gazebo simple_maze.launch.py
```

### 2. Manual Control (Testing)

```bash
# Launch teleop for manual control during testing
ros2 run turtlebot3_teleop teleop_keyboard
```

### 3. SLAM Navigation

```bash
# Launch SLAM for mapping
ros2 launch turtlebot3_cartographer cartographer.launch.py use_sim_time:=True

# Launch navigation stack
ros2 launch turtlebot3_navigation2 navigation2.launch.py use_sim_time:=True
```

## Navigation Features

### **Perfect for Learning**
- **Clean Environment**: No distracting elements, just pure navigation
- **Multiple Paths**: Various routes through the maze for path planning
- **Dead Ends**: Challenges for obstacle avoidance algorithms
- **Open Areas**: Spaces for turning and maneuvering

### **SLAM Testing**
- **Wall Detection**: Clear walls for LiDAR-based SLAM
- **Loop Closure**: Opportunities for map loop closure detection
- **Feature Rich**: Multiple corners and openings for localization
- **Bounded Area**: Defined boundaries for complete mapping

### **Algorithm Development**
- **Path Planning**: Test A*, RRT, or other planning algorithms  
- **Obstacle Avoidance**: Dynamic and static obstacle handling
- **Localization**: Test AMCL and other localization methods
- **Exploration**: Autonomous exploration algorithms

## ROS Topics

The maze world publishes standard TurtleBot3 topics:

- `/scan` - LiDAR data for navigation and mapping
- `/odom` - Odometry for localization  
- `/cmd_vel` - Velocity commands for movement
- `/joint_states` - Robot joint information
- `/imu` - Inertial measurement data
- `/tf` - Transform tree for coordinate frames

## World Specifications

### **Dimensions**
- **Total Area**: 12m x 8m
- **Wall Height**: 1.5m for interior walls, 2m for outer walls
- **Wall Thickness**: 0.2m for reliable collision detection
- **Floor**: Flat gray surface with proper friction

### **Lighting**
- **Directional Light**: Main overhead lighting
- **Point Lights**: Two additional lights for even illumination
- **Shadows**: Enabled for realistic visual feedback

### **Physics**
- **Simulation**: ODE physics engine
- **Step Size**: 0.001s for accurate simulation
- **Real-time Factor**: 1.0 for real-time performance
- **Collision**: Proper collision detection for all walls

## Customization

### Adding More Walls
Edit `simple_maze.world` to add additional maze walls:

```xml
<model name="maze_wall_9">
  <static>true</static>
  <link name="link">
    <visual name="visual">
      <geometry>
        <box>
          <size>length width height</size>
        </box>
      </geometry>
    </visual>
    <collision name="collision">
      <geometry>
        <box>
          <size>length width height</size>
        </box>
      </geometry>
    </collision>
  </link>
  <pose>x y z 0 0 0</pose>
</model>
```

### Modifying Start Position
Change the robot spawn position by editing the launch file:
```python
x_pose = LaunchConfiguration('x_pose', default='your_x')
y_pose = LaunchConfiguration('y_pose', default='your_y')
```

### Adding Landmarks
Place markers for navigation testing:
- QR codes on walls for localization
- ArUco markers for visual navigation
- Colored objects for detection testing

The mission world already includes two static ArUco marker boards (`aruco_marker_0` and `aruco_marker_1`) placed in the corridor so camera-based detection can work in Gazebo.

## Performance Tips

### **Simulation Performance**
- Reduce physics step size if simulation is too fast
- Increase step size if simulation is too slow
- Adjust lighting for better visual performance

### **Navigation Tuning**
- Adjust LiDAR parameters for better wall detection
- Tune SLAM parameters for the maze size
- Configure navigation stack for maze-specific challenges

## Troubleshooting

### Common Issues

1. **Robot doesn't spawn**: Check TURTLEBOT3_MODEL environment variable
2. **Walls not detected**: Verify LiDAR range and angle settings  
3. **Poor performance**: Reduce physics step size or complexity
4. **Navigation issues**: Check coordinate frames and transforms

### **Maze Too Easy/Hard?**
- **Too Easy**: Add more walls and complexity
- **Too Hard**: Remove some walls or widen passages
- **Just Right**: Perfect for learning and testing!

## Files Structure

```
turtlebot3_gazebo/
├── worlds/
│   └── simple_maze.world          # Main maze world file  
├── launch/
│   └── simple_maze.launch.py      # Launch simple maze simulation
└── README_maze.md                 # This documentation
```

This simple maze world provides the perfect foundation for learning autonomous navigation, developing SLAM algorithms, and testing path planning without the complexity of delivery missions or multi-level environments! 🤖🗺️

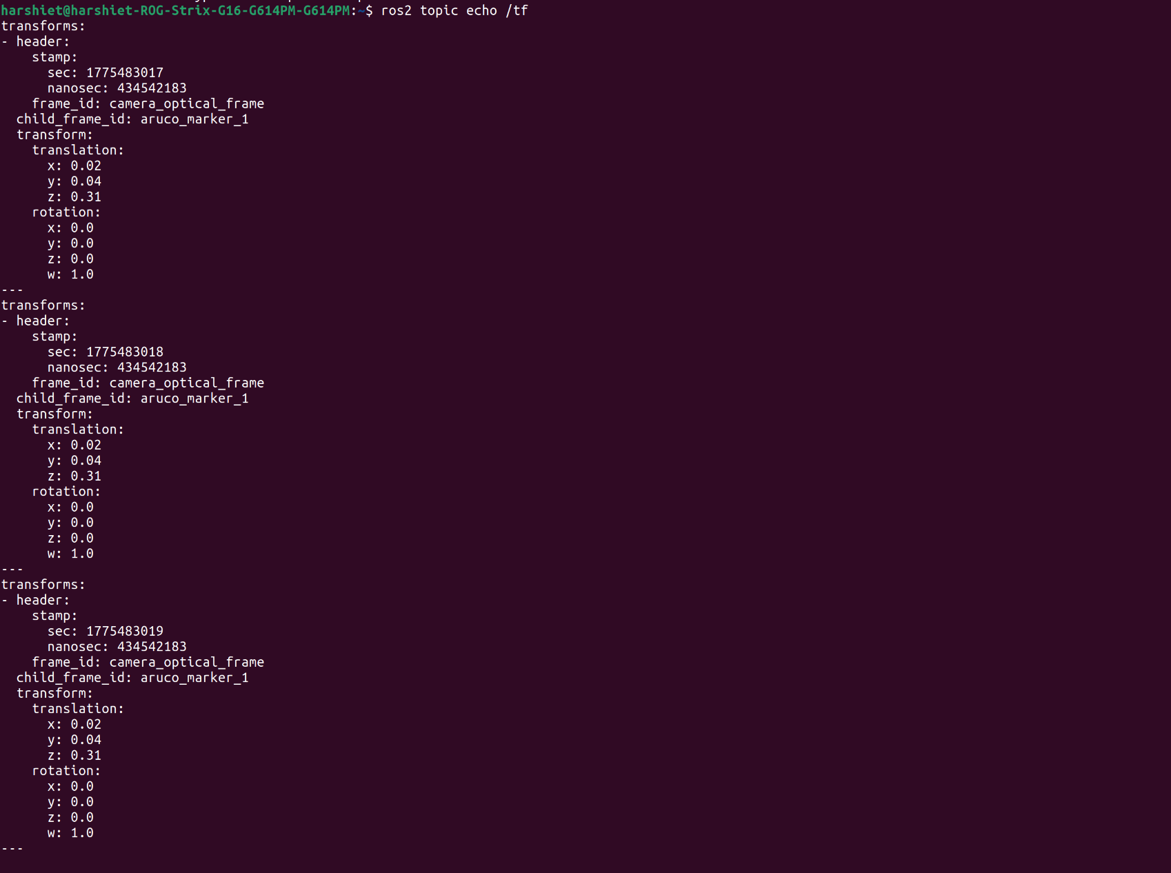
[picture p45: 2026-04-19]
testing-media/images/Aruco_tf.png

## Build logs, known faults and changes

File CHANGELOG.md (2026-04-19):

## [2.16.10] - 2026-04-19
Updated the documentation site's theme, expanded main navigation, and refined content.

### Documentation
- docs(site): Updated Jekyll theme configuration and site-wide HTML structure.
- docs(navigation): Expanded main navigation to include all major documentation sections.
- docs(navigation): Refined "System Overview" heading and clarified Navigation System Flowchart.

## [2.16.9] - 2026-04-19
Added comprehensive documentation for the mechanical subsystem and an appendix.

### Documentation
- docs(mechanical): Documented the mechanical subsystem, covering design, assembly, BOM, actuator mechanics, and iterative changes.
- docs(appendix): Added an appendix with RViz configuration and ping pong ball release height calculations.

## [2.16.8] - 2026-04-19
Expanded and updated the testing documentation with detailed physical robot test results and subsystem summaries for ArUco marker detection and docking.

### Documentation
- docs(testing): Added comprehensive physical robot testing results and summaries for the ArUco marker detection subsystem.
- docs(testing): Documented physical robot testing results and summaries for the docking subsystem, including the evolution of its control logic.
- docs(testing): Updated integration testing procedures and expected behaviors for marker detection and full system bringup.

## [2.16.7] - 2026-04-19
Enhanced the Concept of Operations document with a visual representation of the system's workflow.

### Documentation
- docs(con-ops): Added a system workflow flowchart to the Concept of Operations document.

## [2.16.6] - 2026-04-19
Comprehensive update to the ArUco marker detection software subsystem documentation.

### Documentation
- docs(aruco): Provided comprehensive documentation for the ArUco marker detection subsystem, detailing its design, detection pipeline, core interfaces (topics, parameters), pose estimation, TF publication, debug behavior, and verification procedures.

## [2.16.5] - 2026-04-19

### Documentation
- docs(fsm): Updated the Finite State Machine documentation to align with implementation, including the addition of a BACKUP state, clarification of velocity multiplexing, and revised state descriptions and transition triggers.

## [2.16.4] - 2026-04-19
Refined the High Level Design document with expanded details on system architecture, data flow, and subsystem operations.

### Fixed
- fix(docs): Removed the redundant 'docshigh-level-design.md' file.

### Documentation
- docs(high-level-design): Expanded and refined the High Level Design document with detailed sections on system overview, deployment, data flow, mission states, and subsystem descriptions.

## [2.16.3] - 2026-04-19
### Documentation
- docs(high-level-design): Added a comprehensive High Level Design document detailing system architecture, data flow, mission states, and subsystem descriptions.

## [2.16.2] - 2026-04-19
### Documentation
- docs(requirements-spec): Added a comprehensive requirements specification document covering functional, non-functional, performance, and safety requirements.

# Changelog
## [2.16.1] - 2026-04-18
### Documentation
- docs(con-ops): Expanded the Concept of Operations document with detailed mission phases, system overview, operational sequences, and fault recovery scenarios.

## [2.16.0] - 2026-04-18
Iterative redesign of the payload launcher for improved feeding, increased launch force, and reduced gear slipping, based on testing results.
### Added / Changed
- feat(payload): Added servo gate mount
- feat (payload): launcher design iteration to prevent gear slipping (add servo cover, reduce servo screw hole diameter, reduce gear distance, increase wall thickness to reduce launcher flex)
- feat (payload): moved ball stop further up to reduce feeding jam and increase launch distance
- feat (payload): side wall addition to prevent ball rolling out during feeding
- feat (payload): increased launcher tilt to reduce ball falling out of launcher

## [2.15.1] - 2026-04-18
### Documentation
- docs(interface): Documented ROS topic specifications, launch arguments, timing, and error handling.
- docs(subsystem): Completed navigation and FSM subsystem design, state flow, and parameter tuning.
- docs(development): Added configuration management guide and comprehensive troubleshooting procedures.

## [2.15.0] - 2026-04-17
### Added / Changed
- feat(navigation): Enhanced frontier group selection and local obstacle avoidance in exploration.
- feat(marker): Implemented a `/marker_detected` publisher in `Pose_publisher_V2_TF2.py` to indicate Aruco marker visibility.

### Fixed
- fix(shooter): Reverted and reorganized shooter delivery logic, including dynamic shot counting, and fine-tuned pinion engagement trim parameters for consistency.
- fix(fsm): Improved FSM handling of docking failures and marker loss during docking.

### Testing
- test(shooter): Added a standalone servo isolation test script (`servo_isolation_test.py`).

## [2.14.1] - 2026-04-16
### Fixed
- fix(docking): Recalibrated docking parameters in `docking_controller.py` by adjusting `mid_tz_threshold` to `0.30` and introducing a corrective turn during final alignment for improved centering.

## [2.14.0] - 2026-04-15
Introduced a two-pass dynamic delivery sequence for the shooter and improved RViz launch robustness.

### Added / Changed
- feat(shooter): Implemented a two-pass dynamic delivery sequence in `shooter_controller.py`, separating loading and launching phases for dynamic shots.
- feat(launch): Added environment variable prefix to the RViz node in `nav_bringup.py` for cleaner launch and debugging.

### Fixed
- fix(auto_explore): Corrected a typo in the parameter retrieval method for 'marker_size_m' in `pose_publisher.py`.

## [2.13.2] - 2026-04-15
Finalized fine-tuned shooting parameters for improved performance and updated Aruco marker detection.

### Fixed
- fix(shooter): Fine-tuned multiple shooting parameters in `shooter_controller.py`, including `gate_settle_s` to `0.225`, `ball_drop_s` to `0.225`, `disengage_trim_per_extra_cycle_s` to `0.015`, `disengage_trim_per_extra_cycle_high_s` to `0.015`, `rack_hold_duration_s` to `0.2`, `rack_cycle_pause_s` to `0.3`, `delivery2_delay` to `0.1`, `delivery3_delay` to `7.1`, and adjusted `engage_profiles` values. The default `engage_profile` in `_get_engage_time_for_cycle` was also changed to `mild`.
- fix(auto_explore): Adjusted the `marker_size_m` parameter in `pose_publisher.py` from `0.053` to `0.049` for improved Aruco marker detection accuracy.

### Documentation
- docs(shooter): Added instructions to `README.md` for activating the shooter node using `ros2 topic pub` commands for static and dynamic shooting.

## [2.13.1] - 2026-04-15
### Fixed
- fix(docking): Implemented new watchdog timers (30s marker invisibility, 45s state timeout) in `docking_controller.py` to prevent the robot from getting stuck during docking.
- fix(docking): Refactored state transitions in `docking_controller.py` to use a dedicated `set_state` method, ensuring consistent state management and watchdog resets.
- fix(docking): Renamed the `MoveOnAruco` node to `DockingController` and adjusted `mid_tz_threshold` to 0.50 in `docking_controller.py`.

## [2.13.0] - 2026-04-15
Streamlined exploration by removing the yaw rotation sweep at waypoints and introduced a new tight maze simulation environment.

### Added / Changed
- feat(exploration): Eliminated the yaw rotation sweep at waypoints in `exploration_controller.py`, allowing the robot to transition immediately to the next waypoint for improved navigation efficiency.
- feat(simulation): Added a new `tight_maze.world` Gazebo environment for testing navigation in constrained spaces.

## [2.12.0] - 2026-04-15
Major refactor of the docking controller, introduction of delayed startup for SLAM and RViz, and various parameter tunings for SLAM and shooter.

### Added / Changed
- feat(docking): Reworked the `docking_controller.py` FSM to a simpler align-and-approach logic, introducing new configurable parameters for approach speed, angular speed, alignment gain, tolerances, and docking distance.
- feat(launch): Added `slam_start_delay_sec` and `rviz_start_delay_sec` launch arguments to `nav_bringup.py` to delay SLAM Toolbox and RViz startup using `TimerAction`.
- feat(launch): Introduced `enable_pose_publisher` launch argument in `global_bringup.py` and `global_controller_bringup.py` to conditionally enable the `pose_publisher` node.

### Fixed
- fix(slam): Adjusted `throttle_scans`, `minimum_time_interval`, `transform_timeout`, `tf_buffer_duration`, and `scan_buffer_size` in `mapper_params_online_async.yaml` to improve SLAM stability and TF message handling.
- fix(shooter): Tuned `gate_settle_s` and `ball_drop_s` parameters in `shooter_controller.py` for improved timing.

### Documentation
- docs(setup): Updated `README.md` with `shooter_pigpiod_host` in launch commands and added a reusable `start` shell function for simplified deployment.

## [2.11.2] - 2026-04-14
Refined the initial approach distance for the docking maneuver.

### Fixed
- fix(Docking): Adjusted the `mid_tz_threshold` parameter in `docking_controller.py` from 0.50 to 0.30 to refine the initial straight approach limit during docking.

## [2.11.1] - 2026-04-14
Ensured the shooter node has sufficient time to complete its operation during the launch sequence.

### Fixed
- fix(FSM): Implemented a minimum duration for the 'LAUNCH' state in `mission_controller.py` using `launch_min_duration_sec` to ensure the shooter node completes its cycle.
- fix(FSM): Refined 'LAUNCH' state management in `mission_controller.py` to correctly handle `launch_completion_pending` and `launch_start_time` for robust shooter operation.

## [2.11.0] - 2026-04-14
Implemented a new post-launch backup maneuver to prevent collisions and adjusted the robot's yaw sweep rotation speed.

### Added / Changed
- feat(state): Implemented a new "BACKUP" state in `mission_controller.py` that triggers after a launch sequence, causing the robot to move backward at -0.1 m/s for 2 seconds before returning to exploration.
- feat(auto_explore): Reduced the yaw sweep angular velocity in `exploration_controller.py` from `math.pi / 2` (90 deg/s) to `math.pi / 6` (30 deg/s).

## [2.10.1] - 2026-04-14
### Fixed
- fix(FSM): Removed the `/zone` topic publisher and its associated logic from `mission_controller.py`.

## [2.10.0] - 2026-04-14
Implemented a new post-waypoint behavior for the robot to perform a yaw sweep, enhancing its ability to locate objects after reaching a destination.

### Added / Changed
- feat(auto_explore): Added yaw sweep functionality to `exploration_controller.py`, enabling the robot to perform a 360-degree rotation after reaching a waypoint to search for Aruco codes.

## [2.9.6] - 2026-04-14
Integrated a robust, filtered ultrasonic sensing system for improved dynamic payload delivery.

### Fixed
- fix(shooter): Implemented a new callback-based ultrasonic measurement system in `shooter_controller.py` using `pigpio.EITHER_EDGE` callbacks for improved accuracy.
- fix(shooter): Added new parameters for ultrasonic filtering and calibration: `ultrasonic_sample_count`, `ultrasonic_sample_gap_s`, `ultrasonic_min_distance_m`, `ultrasonic_max_distance_m`, and `ultrasonic_temperature_c`.
- fix(shooter): Implemented median filtering for ultrasonic distance readings and a temperature-compensated `_speed_of_sound_m_s` calculation.
- fix(shooter): Ensured proper cleanup of the ultrasonic callback and `ultrasonic_trigger_pin` in `destroy_node`.

## [2.9.5] - 2026-04-13
Tuned various shooter parameters and refined timing logic for improved static payload delivery.

### Fixed
- fix(shooter): Adjusted `gate_close_us`, `gate_settle_s`, `engage_to_gate_open_offset_s`, `ball_drop_s`, `close_to_release_s`, `rack_hold_duration_s`, and `rack_cycle_pause_s` in `shooter_controller.py`.
- fix(shooter): Renamed `engage_trim_per_extra_cycle_s` and `engage_trim_per_extra_cycle_high_s` to `disengage_trim_per_extra_cycle_s` and `disengage_trim_per_extra_cycle_high_s` respectively, updating their values.
- fix(shooter): Updated `engage_us` and `engage_time_s` for the 'medium' engage profile, and refined the `_get_disengage_pause_for_cycle` logic for cycle-dependent disengage pauses.
- fix(shooter): Modified the `_shoot_once_hardware` function to ensure `engage_thread.join()` timing is independent of gate timing.

## [2.9.4] - 2026-04-13
Integrated shooter testbed into auto_explore package. Updated the auto_explore shooter subsystem to support real-hardware operation via pigpio (remote pigpiod) and adds launch/documentation wiring for the new shooter configuration options.

### Fixed
- fix(shooter): Added shooter launch arguments for pigpiod connection details and ultrasonic/delivery tuning, and forwarded them into shooter_controller.
- fix(shooter): Refactored shooter_controller to use pigpio, add delivery modes (static/dynamic/bonus), and run delivery asynchronously with a busy lock.

### Documentation
- docs(README): Updated README/changelog documentation for the new shooter setup and arguments.

## [2.9.3] - 2026-04-12
Refactored the shooter node's architecture to use `pigpio` for gate control, improved the shooting sequence, and ensured proper GPIO cleanup.

### Fixed
- fix(shooter): Architecturally refactored the shooter node (`Payload_Delivery.py`) to use `pigpio` for SG90 gate servo control, enabling parallel rack engagement and gate operation via threading, and corrected the shooting sequence logic. This included proper resource cleanup in `destroy_node()` and refined pinion timing parameters in `Pinion_Rotation.py`. Added offset tuning parameters for control over servo gate & pinion gear activation timing sequence for real world finetuning.

## [2.9.2] - 2026-04-12
Refactored parameter loading for navigation and SLAM to use ROS 2 parameter server mechanisms, and removed the redundant marker logger.

### Fixed
- fix(navigation): Migrated `exploration_controller` to retrieve navigation tuning parameters from the ROS 2 parameter server, deprecating the previous direct YAML file access.
- fix(slam): Implemented dynamic loading of SLAM Toolbox parameters through a new `slam_params_file` launch argument, referencing `mapper_params_online_async.yaml`.
- fix(logging): Discontinued the `pose_subscriber` node, along with its launch arguments and console entry points, due to its redundant marker logging functionality.

### Documentation
- docs(README): Revised `README.md` to document the removal of the marker logger and include a new section for troubleshooting launch file updates.

## [2.9.2] - 2026-04-12
Refined docking activation logic so the docking controller only engages when the FSM is in the docking state, preventing unintended docking behaviour during other mission phases.

### Fixed
- fix(docking): Updated `docking_controller.py` to subscribe to the `/states` topic and track the robot's overall FSM state before initiating docking.
- fix(docking): Modified the docking controller to remain in `IDLE` by default and only transition to `SEARCH` when the FSM publishes `"DOCK"` on `/states`, ensuring docking logic is gated by the main robot state machine.
- fix(docking): Prevented the docking state machine from starting automatically whenever marker data is available, reducing unintended activation outside the intended docking phase.

## [2.9.1] - 2026-04-12
Refactored parameter loading for navigation and SLAM to use ROS 2 parameter server mechanisms, and removed the redundant marker logger.

### Fixed
- fix(navigation): Updated `exploration_controller` to load navigation tuning parameters directly from the ROS 2 parameter server, replacing direct YAML file parsing.
- fix(slam): Integrated SLAM Toolbox parameters via a new dedicated configuration file (`mapper_params_online_async.yaml`) and exposed it as a launch argument (`slam_params_file`).
- fix(logging): Removed the `pose_subscriber` node, its associated launch arguments, and entry points, as it provided redundant marker logging functionality.

### Documentation
- docs(README): Updated `README.md` to reflect the removal of the marker logger, its launch argument, and added a new troubleshooting section for launch file changes.

## [2.9.0] - 2026-04-12
Integrated servo-driven pinion for payload delivery, enhanced FSM communication with launch completion signals, and refined shooting timings.

### Added / Changed
- feat(shooter): Integrated `Pinion_Rotation` module for servo-controlled rack and pinion payload delivery, replacing direct GPIO rack control in `Shooter/Payload_Delivery.py`.
- feat(fsm): Implemented publishing to `/launch_done` topic from `Shooter/Payload_Delivery.py` after static, dynamic, or bonus deliveries.
- feat(shooter): Adjusted `PHASE1_DEGREES` to `180` in `Shooter/Pinion_Rotation.py` for improved rack engagement.

### Fixed
- fix(shooter): Updated GPIO pin for gate control from `17` to `12` in `Shooter/Payload_Delivery.py`.
- fix(shooter): Tuned shooting timings, including `delivery2_delay` and servo angle hold duration in `Shooter/Payload_Delivery.py`.
- fix(shooter): Ensured proper motor stop and cleanup after `run_cycle` in `Shooter/Pinion_Rotation.py`.

## [2.8.0] - 2026-04-11
Refined shooter mechanism parameters for enhanced performance and updated documentation for new launch configurations.

### Added / Changed
- feat(shooter): Tuned shooter parameters in `Shooter/Pinion_Rotation.py` for drift calibration and continuous shooting, introducing configurable engagement profiles (mild, medium, strong), per-cycle engagement time trimming, and updated timing parameters (`HOLD_DURATION`, `CYCLE_PAUSE`, `ENGAGE_US`, `DISENGAGE_US`, `ENGAGE_TIME_S`, `DISENGAGE_TIME_S`, `ENGAGE_TRIM_PER_EXTRA_CYCLE_S`, `ENGAGE_TRIM_PER_EXTRA_CYCLE_S_2`, `ENGAGE_MIN_TIME_S`).

### Documentation
- docs(README): Updated `README.md` to include the `shooter_enable_hardware` launch argument and clarified launch command usage.

## [2.7.0] - 2026-04-11

Introduced a new hardware control script for the shooter's rack and pinion mechanism, enabling precise servo-driven engagement and disengagement.

### Added / Changed
- feat(shooter): Implemented `Shooter/Pinion_Rotation.py` to control an MG90S continuous rotation servo for a rack and pinion system using `pigpio` on Raspberry Pi. This includes functions for forward rotation, stopping, timed degree rotation, and a full cycle of engaging, holding, and disengaging the rack.

## [2.6.0] - 2026-04-09
Integrated package updates, enhancing the docking controller with timeout and target marker capabilities, improving the mission controller's zone tracking and launch completion handling, and refining ArUco marker detection. Removed the redundant pose subscriber.

### Added / Changed
- feat(auto_explore.docking): Added `dock_cycle_timeout_sec` and `target_marker_id` parameters to `docking_controller.py` for improved control and specific marker targeting.
- feat(auto_explore.mission_control): Enhanced `mission_controller.py` with dynamic zone tracking via TF, robust launch completion handling, and refined state transitions for docking and exploration.
- feat(auto_explore.aruco): Updated `marker_size_m` to `0.053` and adjusted camera subscription QoS to `qos_profile_sensor_data` in `pose_publisher.py`.
- feat(auto_explore.config): Adjusted `speed` parameter in `params.yaml` to `0.09`.

### Fixed
- fix(auto_explore.aruco): Removed the deprecated `pose_subscriber.py` node.
- fix(auto_explore.docking): Improved `dock_done` publishing logic in `docking_controller.py` to prevent duplicates and log success/failure.
- fix(auto_explore.aruco): Optimized `marker_detected` publishing in `pose_publisher.py` to only trigger on visibility state changes.

## [2.5.0] - 2026-04-09
Implemented advanced zone management in the FSM, enabling dynamic identification and tracking of ArUco marker zones using TF, and preventing re-visitation.

### Added / Changed
- feat(fsm): Implemented dynamic zone identification within `fsm_code.py` by subscribing to `/tf` messages, distinguishing between "static" (`aruco_marker_0`) and "dynamic" (`aruco_marker_1`) zones.
- feat(fsm): Introduced a mechanism in `fsm_code.py` to track and prevent re-visiting already processed zones, ensuring unique marker interactions.
- feat(fsm): Updated the `/zone` publisher in `fsm_code.py` to dynamically publish the identified "static" or "dynamic" zone during "DOCK" and "LAUNCH" states, replacing the previous hardcoded "static" value.
- feat(fsm): Modified the FSM's "EXPLORE" state transition in `fsm_code.py` to require an identified `current_zone` before initiating a "DOCK" sequence.
- feat(fsm): Adjusted `self.required_markers` in `fsm_code.py` from 3 to 2.

## [2.4.1] - 2026-04-09
Refined ArUco marker detection status publishing and improved docking state machine logic.

### Fixed
- fix(marker_detection): Implemented a `/marker_detected` boolean publisher in `Pose_publisher_V2_TF2.py` to indicate ArUco marker visibility.
- fix(docking): Updated `MoveOnAruco` node to use `/cmd_vel_docking` and refined state transitions for `IDLE`, `DONE`, and `ABORT` states in `Aruco_Docker_Final.py`.

## [2.4.0](https://github.com/Kmyming/CDE2310_G10_2526/pull/28) - 2026-04-08
Implemented a command velocity multiplexer within the FSM to dynamically switch between navigation and docking commands, and introduced a "static" zone publisher for docking and launch states.

### Added / Changed
- feat(fsm): Added a command velocity multiplexer in `fsm_code.py` to publish `/cmd_vel` based on the current FSM state, switching between `/cmd_vel_nav` and `/cmd_vel_docking` inputs.
- feat(fsm): Introduced a `/zone` publisher in `fsm_code.py` to indicate "static" zones during "DOCK" and "LAUNCH" states, supporting static/dynamic docking state management.

## [2.3.0] - 2026-04-07
Enhanced exploration visualization and control logic with path publishing capabilities in RViz2 and comprehensive exploration package documentation.

### Added / Changed
- feat(exploration): Added path publishing for exploration visualization in RViz2 to display the robot's navigation path during autonomous exploration.
- feat(exploration): Enhanced path publishing with dynamic start index to provide more granular control over visualization of exploration trajectories.
- feat(exploration): Introduced comprehensive README.md with configuration and usage instructions for the autonomous exploration package.
- feat(exploration): Improved local control logic with enhanced obstacle avoidance and navigation capabilities.
- feat(exploration): Added publisher for map exploration status to notify the FSM of exploration completion.
- feat(config): Adjusted speed parameter in `params.yaml` for improved exploration performance.

### Documentation
- docs(exploration): Added example images for physical test maze to guide manual testing procedures.

## [2.2.0] - 2026-04-07
Implemented autonomous docking capabilities using ArUco markers and enhanced payload delivery servo control.

### Added / Changed
- feat(docking): Introduced a new `MoveOnAruco` node for autonomous docking, utilizing ArUco marker pose data, odometry, and LIDAR for alignment and obstacle avoidance.
- feat(shooting): Added a `set_servo_angle` method for precise servo control in the payload delivery system.

### Fixed
- fix(servo): Corrected the gate opening and closing mechanism in the payload delivery system to use PWM for smoother servo operation.
- fix(aruco): Updated the ArUco pose publisher to correctly detect and process 4x4 ArUco markers.

## [2.1.1] - 2026-03-31
Updated CI workflow documentation to reflect automated changelog generation.

### Documentation
- docs(README): Removed manual instructions for triggering the changelog update, reflecting the automated process.

## [2.1.0] - 2026-03-31
Further enhanced the CI/CD pipeline with automated PR description, review, and code improvement capabilities, alongside comprehensive documentation updates.

### Added / Changed
- feat(ci): Integrated automated PR description, review, and code improvement functionalities into the CI pipeline using the native Python PR-Agent CLI.

### Documentation
- docs(README): Expanded the CI/CD documentation in the README, detailing the AI pipeline steps, manual PR-Agent commands, and including a Mermaid architecture diagram.

## [2.0.0] - 2026-03-31
Major redesign of the launcher payload system, alongside significant enhancements to the CI/CD pipeline for automated changelog generation and PR agent functionality.

### Added / Changed
- feat(payload): Redesigned the launcher payload system, marking a major architectural change.
- feat(cad): Introduced an ultimate pipeline test for CAD assets.
- feat(ci): Implemented native Python CLI execution for PR Agent changelog updates within the CI workflow, including explicit model configuration (`gemini/gemini-2.5-flash`) and refined commit fetching logic.
- feat(ci): implemented an automated commit scraper to read local git history (`git log`) and inject commit messages directly into PR descriptions. This successfully bridges the "binary blindspot," allowing the AI to read physical hardware/CAD updates (`.SLDPRT`, `.STL`) even when the `git diff` is empty.
- feat(ci): added a native Python execution step (`pip install pr-agent`) to trigger the `update_changelog` tool automatically on PR creation, completely bypassing hardcoded event-trigger limitations in the official Qodo Docker image.
- feat(ci): configured PR-Agent to utilize Google's `gemini-2.5-flash` model natively.
- feat(ci): implemented a massive 1,000,000 custom token limit override (`--config.custom_model_max_tokens=1000000`) to prevent the agent from panicking when reading massive hardware repository diffs.

### Documentation
- docs(README): Updated CI documentation and PR agent prompt details in the README.

### Changed
- refactor(ci): transitioned from the official `qodo-ai/pr-agent` Action and Docker image wrappers to a raw CLI execution environment. This prevents environment variable corruption and syntax stripping by the Ubuntu bash runner.
- refactor(ci): shifted model configuration definitions from Bash environment variables to direct CLI arguments (`--config.model="..."`) to bypass the buggy Dynaconf settings parser.

### Fixed
- fix(ci): pinned the `httpx` library to `<0.28.0` in the GitHub Actions runner to prevent fatal `AsyncClient.__init__()` proxy crashes inside the LiteLLM router when falling back to default models.
- fix(ci): resolved `400 Invalid API Key` and LiteLLM authentication errors by routing the GitHub secret explicitly to the `GEMINI_API_KEY` variable required by the native Python environment.

## [1.2.0](https://github.com/Kmyming/CDE2310_G10_2526/pull/18) - 2026-03-31

Integrate marker detection into the FSM, adding a new subscriber and refining callback logic for robust state transitions.

### Added
- feat(fsm): Added a new subscriber for the `/marker_detected` topic in `FSM/fsm_code.py`.

### Fixed
- fix(fsm): Refined the `aruco_callback` logic in `FSM/fsm_code.py` to correctly check `msg.data` in addition to the FSM being in the "EXPLORE" state before setting `self.marker_detected`.

## [1.1.0](https://github.com/Kmyming/CDE2310_G10_2526/pull/17) - 2026-03-26

Refactored the FSM state machine logic, removing obsolete components, improving state transition reliability, and enhancing overall mission control clarity.

### Added / Changed
- feat(fsm): Increased the `required_markers` count from 2 to 3 in `FSM/fsm_code.py`.
- feat(fsm): Improved logging messages for state transitions and added type hints for callback functions in `FSM/fsm_code.py`.

### Fixed
- fix(fsm): Removed unused `PoseStamped` import, `current_marker_pub` publisher, and `aruco_pose` subscriber from `FSM/fsm_code.py`.
- fix(fsm): Refined the `EXPLORE` state logic in `FSM/fsm_code.py` to correctly transition to `DOCK` or `END`, removing a redundant `self.change_state("EXPLORE")` call.
- fix(fsm): Added `self.timer.cancel()` in the `END` state of `FSM/fsm_code.py` to stop the state machine loop and prevent continuous logging after mission completion.

## [1.0.0] - 2026-03-20

Complete architectural refactor: Independent `auto_explore` mission control system with modular ROS2 launch architecture, proper package discovery, and updated documentation.

### Added
- feat(architecture): Create independent `auto_explore` mission control system with zero external imports
- feat(launch): Implement modular launch architecture with 3 components (nav_bringup, global_controller_bringup, global_bringup)
- feat(fsm): Port FSM state machine from legacy implementation to `mission_controller.py`
- feat(navigation): Port frontier-based exploration algorithm from legacy to `exploration_controller.py`
- feat(markers): Port ArUco marker detection from legacy to `pose_publisher.py`
- feat(markers): Port marker logging system from legacy to `pose_subscriber.py`
- feat(config): Create local `config/params.yaml` for exploration parameter tuning (lookahead_distance, speed, expansion_size, target_error, robot_r)
- feat(package): Implement proper ROS2 ament_python package structure with correct buildtool_depend and export section
- fix(discovery): Fix package discovery issue by removing redundant exec_depend entries and setting packages=[package_name] in setup.py
- docs(README): Update README.md with clear Gazebo and physical robot launch sequences
- docs(README): Update installation instructions for `auto_explore` package
- docs(README): Keep legacy instructions for `autonomous_exploration` package for reference

### Changed
- refactor(architecture): Refactored entire mission control system from nested repository structure to independent package
- refactor(package): Updated package discovery mechanism to use ROS2 standard conventions

### Fixed
- fix(discovery): Fixed package discovery type changed from `(python)` to `(ros.ament_python)`
- fix(package): Resolved XML parsing errors by removing mixed depend/exec_depend entries
- fix(launcher): Fixed launch wrapper script dependency by properly registering package with ROS2
- fix(setup): Removed wrapper script dependency - now uses direct `ros2 launch` command
- fix(config): Removed redundant exec_depend entries from package.xml
- fix(rviz): Cleaned up orphaned RViz configuration files

### Technical Details
- **Package Name:** `auto_explore`
- **Build System:** ament_python
- **ROS2 Version:** Humble
- **Python Version:** 3.x
- **Key Dependencies:** rclpy, geometry_msgs, sensor_msgs, nav_msgs, std_msgs, cv_bridge, opencv-python, pyyaml, slam_toolbox, rviz2
  
---
All notable changes to this project will be documented in this file.

The format is based on [Keep a Changelog](https://keepachangelog.com/en/1.0.0/),
and this project adheres to [Semantic Versioning](https://semver.org/spec/v2.0.0.html).

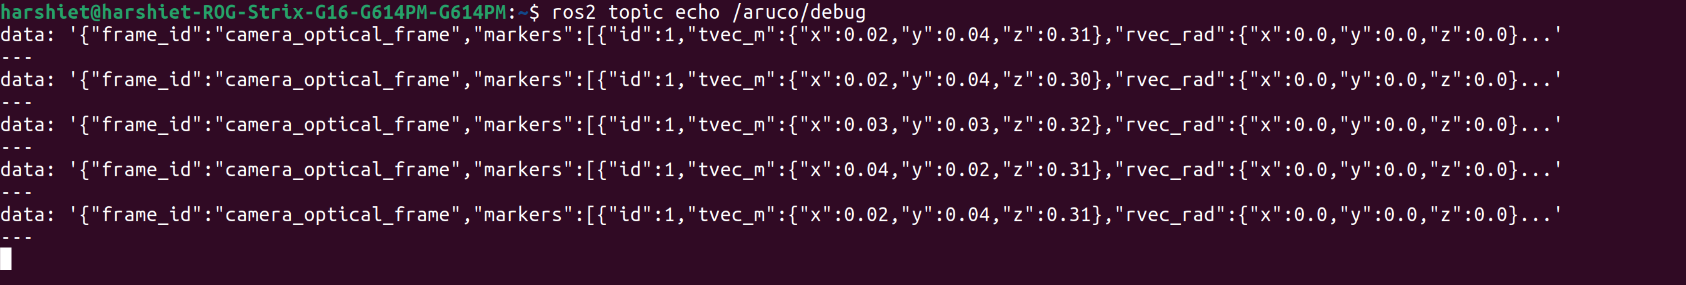
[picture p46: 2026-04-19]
testing-media/images/Aruco_aruco_debug.png

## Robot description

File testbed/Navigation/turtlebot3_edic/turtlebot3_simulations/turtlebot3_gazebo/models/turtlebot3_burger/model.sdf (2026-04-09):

<?xml version="1.0" ?>
<sdf version="1.5">
  <model name="turtlebot3_burger">
    <pose>0.0 0.0 0.0 0.0 0.0 0.0</pose>

    <link name="base_footprint"/>

    <link name="base_link">

      <inertial>
        <pose>-0.032 0 0.070 0 0 0</pose>
        <inertia>
          <ixx>7.2397393e-01</ixx>
          <ixy>4.686399e-10</ixy>
          <ixz>-1.09525703e-08</ixz>
          <iyy>7.2397393e-01</iyy>
          <iyz>2.8582649e-09</iyz>
          <izz>6.53050163e-01</izz>
        </inertia>
        <mass>8.2573504e-01</mass>
      </inertial>

      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
    </link>

    <link name="imu_link">
      <sensor name="tb3_imu" type="imu">
        <always_on>true</always_on>
        <update_rate>200</update_rate>
        <topic>imu</topic>
        <imu>
          <angular_velocity>
            <x>
              <noise type="gaussian">
                <mean>0.0</mean>
                <stddev>2e-4</stddev>
              </noise>
            </x>
            <y>
              <noise type="gaussian">
                <mean>0.0</mean>
                <stddev>2e-4</stddev>
              </noise>
            </y>
            <z>
              <noise type="gaussian">
                <mean>0.0</mean>
                <stddev>2e-4</stddev>
              </noise>
            </z>
          </angular_velocity>
          <linear_acceleration>
            <x>
              <noise type="gaussian">
                <mean>0.0</mean>
                <stddev>1.7e-2</stddev>
              </noise>
            </x>
            <y>
              <noise type="gaussian">
                <mean>0.0</mean>
                <stddev>1.7e-2</stddev>
              </noise>
            </y>
            <z>
              <noise type="gaussian">
                <mean>0.0</mean>
                <stddev>1.7e-2</stddev>
              </noise>
            </z>
          </linear_acceleration>
        </imu>
      </sensor>
    </link>

    <link name="base_scan">
      <inertial>
        <pose>-0.020 0 0.161 0 0 0</pose>
        <inertia>
          <ixx>0.001</ixx>
          <ixy>0.000</ixy>
          <ixz>0.000</ixz>
          <iyy>0.001</iyy>
          <iyz>0.000</iyz>
          <izz>0.001</izz>
        </inertia>
        <mass>0.114</mass>
      </inertial>

      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

      <sensor name="hls_lfcd_lds" type="gpu_lidar">
        <always_on>true</always_on>
        <visualize>true</visualize>
        <pose>-0.032 0 0.171 0 0 0</pose>
        <update_rate>5</update_rate>
        <topic>scan</topic>
        <gz_frame_id>base_scan</gz_frame_id>
        <lidar>
          <scan>
            <horizontal>
              <samples>360</samples>
              <resolution>1.000000</resolution>
              <min_angle>0.000000</min_angle>
              <max_angle>6.280000</max_angle>
            </horizontal>
          </scan>
          <range>
            <min>0.120000</min>
            <max>3.5</max>
            <resolution>0.015000</resolution>
          </range>
          <noise>
            <type>gaussian</type>
            <mean>0.0</mean>
            <stddev>0.01</stddev>
          </noise>
        </lidar>
      </sensor>
    </link>

    <link name="camera_link"/>

    <link name="camera_rgb_frame">
      <inertial>
        <pose>0.069 -0.047 0.107 0 0 0</pose>
        <inertia>
          <ixx>0.001</ixx>
          <ixy>0.000</ixy>
          <ixz>0.000</ixz>
          <iyy>0.001</iyy>
          <iyz>0.000</iyz>
          <izz>0.001</izz>
        </inertia>
        <mass>0.035</mass>
      </inertial>

      <pose>0.069 -0.047 0.107 0 0 0</pose>
      <sensor name="camera" type="camera">
        <always_on>true</always_on>
        <visualize>true</visualize>
        <update_rate>30</update_rate>
        <topic>camera/image_raw</topic>
        <gz_frame_id>camera_rgb_frame</gz_frame_id>
        <camera name="intel_realsense_r200">
          <camera_info_topic>camera/camera_info</camera_info_topic>
          <horizontal_fov>1.02974</horizontal_fov>
          <image>
            <width>640</width>
            <height>480</height>
            <format>R8G8B8</format>
          </image>
          <clip>
            <near>0.02</near>
            <far>30</far>
          </clip>
          <noise>
            <type>gaussian</type>
            <mean>0.0</mean>
            <stddev>0.007</stddev>
          </noise>
        </camera>
      </sensor>
    </link>

    <link name="wheel_left_link">

      <inertial>
        <pose>0 0.08 0.023 -1.57 0 0</pose>
        <inertia>
          <ixx>1.8158194e-03</ixx>
          <ixy>-9.3392e-12</ixy>
          <ixz>1.04909e-11</ixz>
          <iyy>3.2922126e-03</iyy>
          <iyz>5.75694e-11</iyz>
          <izz>1.8158194e-03</izz>
        </inertia>
        <mass>2.8498940e-02</mass>
      </inertial>

      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
    </link>

    <link name="wheel_right_link">

      <inertial>
        <pose>0.0 -0.08 0.023 -1.57 0 0</pose>
        <inertia>
          <ixx>1.8158194e-03</ixx>
          <ixy>-9.3392e-12</ixy>
          <ixz>1.04909e-11</ixz>
          <iyy>3.2922126e-03</iyy>
          <iyz>5.75694e-11</iyz>
          <izz>1.8158194e-03</izz>
        </inertia>
        <mass>2.8498940e-02</mass>
      </inertial>

      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
    </link>

    <joint name="camera_joint" type="fixed">
      <parent>base_link</parent>
      <child>camera_link</child>
      <pose>0.064 -0.065 0.094 0 0 0</pose>
      <axis>
        <xyz>0 0 1</xyz>
      </axis>
    </joint>

    <joint name="camera_rgb_joint" type="fixed">
      <parent>camera_link</parent>
      <child>camera_rgb_frame</child>
      <pose>0.005 0.018 0.013 0 0 0</pose>
      <axis>
        <xyz>0 0 1</xyz>
      </axis>
    </joint>

    <link name='caster_back_link'>
      <pose>-0.081 0 -0.004 -1.57 0 0</pose>
      <inertial>
        <mass>0.005</mass>
        <inertia>
          <ixx>0.001</ixx>
          <ixy>0.000</ixy>
          <ixz>0.000</ixz>
          <iyy>0.001</iyy>
          <iyz>0.000</iyz>
          <izz>0.001</izz>
        </inertia>
      </inertial>
      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
    </link>

    <joint name="base_joint" type="fixed">
      <parent>base_footprint</parent>
      <child>base_link</child>
      <pose>0.0 0.0 0.010 0 0 0</pose>
    </joint>

    <joint name="wheel_left_joint" type="revolute">
      <parent>base_link</parent>
      <child>wheel_left_link</child>
      <pose>0.0 0.08 0.023 -1.57 0 0</pose>
      <axis>
        <xyz>0 0 1</xyz>
        <limit>
            <effort>20</effort>
        </limit>
      </axis>
    </joint>

    <joint name="wheel_right_joint" type="revolute">
      <parent>base_link</parent>
      <child>wheel_right_link</child>
      <pose>0.0 -0.08 0.023 -1.57 0 0</pose>
      <axis>
        <xyz>0 0 1</xyz>
        <limit>
            <effort>20</effort>
        </limit>
      </axis>
    </joint>

    <joint name='caster_back_joint' type='ball'>
      <parent>base_link</parent>
      <child>caster_back_link</child>
    </joint>

    <joint name="imu_joint" type="fixed">
      <parent>base_link</parent>
      <child>imu_link</child>
      <pose>-0.032 0 0.068 0 0 0</pose>
      <axis>
        <xyz>0 0 1</xyz>
      </axis>
    </joint>

    <joint name="lidar_joint" type="fixed">
      <parent>base_link</parent>
      <child>base_scan</child>
      <pose>-0.032 0 0.171 0 0 0</pose>
      <axis>
        <xyz>0 0 1</xyz>
      </axis>
    </joint>

    <plugin filename="gz-sim-diff-drive-system" name="gz::sim::systems::DiffDrive">

      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
      <left_joint>wheel_left_joint</left_joint>
      <right_joint>wheel_right_joint</right_joint>

      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
      <wheel_separation>0.160</wheel_separation>
      <wheel_radius>0.033</wheel_radius>

      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
      <max_linear_acceleration>1.0</max_linear_acceleration>

      <topic>cmd_vel</topic>

      <odom_topic>odom</odom_topic>
      <frame_id>odom</frame_id>
      <child_frame_id>base_footprint</child_frame_id>
      <odom_publisher_frequency>30</odom_publisher_frequency>
      <tf_topic>/tf</tf_topic>

    </plugin>
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

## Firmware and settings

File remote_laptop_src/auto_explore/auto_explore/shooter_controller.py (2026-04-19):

#!/usr/bin/env python3

import threading
import time

import rclpy
from rclpy.node import Node

from std_msgs.msg import Bool, String


class ShooterController(Node):
    def __init__(self):
        super().__init__('shooter_controller')

        # Safety-first defaults for Gazebo/subsystem tests.
        self.declare_parameter('enable_hardware', False)
        self.declare_parameter('simulated_shot_delay_sec', 1.5)
        self.declare_parameter('pigpiod_host', 'localhost')
        self.declare_parameter('pigpiod_port', 8888)
        self.declare_parameter('gate_pin', 12)
        self.declare_parameter('rack_pin', 13)
        self.declare_parameter('ultrasonic_trigger_pin', 23)
        self.declare_parameter('ultrasonic_echo_pin', 24)
        self.declare_parameter('ultrasonic_distance_threshold_m', 0.70)
        self.declare_parameter('ultrasonic_simulated_distance_m', 0.15)
        self.declare_parameter('gate_open_us', 500)
        self.declare_parameter('gate_close_us', 1000)
        self.declare_parameter('gate_settle_s', 0.225)
        self.declare_parameter('engage_to_gate_open_offset_s', 0.35)
        self.declare_parameter('ball_drop_s', 0.225)
        self.declare_parameter('close_to_release_s', 0.03125)
        self.declare_parameter('engage_profile', 'medium')
        self.declare_parameter('disengage_trim_per_extra_cycle_s', 0.015)
        self.declare_parameter('disengage_trim_per_extra_cycle_high_s', 0.015)
        self.declare_parameter('rack_hold_duration_s', 0.2)
        self.declare_parameter('rack_cycle_pause_s', 0.3)
        self.declare_parameter('dynamic_poll_interval_s', 0.05)

        # Legacy params retained for compatibility.
        self.declare_parameter('ultrasonic_echo_timeout_s', 0.03)

        # New ultrasonic filtering params from the tested node.
        self.declare_parameter('ultrasonic_sample_count', 5)
        self.declare_parameter('ultrasonic_sample_gap_s', 0.06)
        self.declare_parameter('ultrasonic_min_distance_m', 0.02)
        self.declare_parameter('ultrasonic_max_distance_m', 4.0)
        self.declare_parameter('ultrasonic_temperature_c', 25.0)

        self.enable_hardware = bool(self.get_parameter('enable_hardware').value)
        self.simulated_shot_delay_sec = float(self.get_parameter('simulated_shot_delay_sec').value)
        self.pigpiod_host = str(self.get_parameter('pigpiod_host').value).strip()
        self.pigpiod_port = int(self.get_parameter('pigpiod_port').value)
        self.gate_pin = int(self.get_parameter('gate_pin').value)
        self.rack_pin = int(self.get_parameter('rack_pin').value)
        self.ultrasonic_trigger_pin = int(self.get_parameter('ultrasonic_trigger_pin').value)
        self.ultrasonic_echo_pin = int(self.get_parameter('ultrasonic_echo_pin').value)
        self.ultrasonic_distance_threshold_m = float(
            self.get_parameter('ultrasonic_distance_threshold_m').value
        )
        self.ultrasonic_simulated_distance_m = float(
            self.get_parameter('ultrasonic_simulated_distance_m').value
        )
        self.gate_open_us = int(self.get_parameter('gate_open_us').value)
        self.gate_close_us = int(self.get_parameter('gate_close_us').value)
        self.gate_settle_s = float(self.get_parameter('gate_settle_s').value)
        self.engage_to_gate_open_offset_s = float(
            self.get_parameter('engage_to_gate_open_offset_s').value
        )
        self.ball_drop_s = float(self.get_parameter('ball_drop_s').value)
        self.close_to_release_s = float(self.get_parameter('close_to_release_s').value)
        self.engage_profile = str(self.get_parameter('engage_profile').value).strip().lower()
        self.disengage_trim_per_extra_cycle_s = float(
            self.get_parameter('disengage_trim_per_extra_cycle_s').value
        )
        self.disengage_trim_per_extra_cycle_high_s = float(
            self.get_parameter('disengage_trim_per_extra_cycle_high_s').value
        )
        self.rack_hold_duration_s = float(self.get_parameter('rack_hold_duration_s').value)
        self.rack_cycle_pause_s = float(self.get_parameter('rack_cycle_pause_s').value)
        self.dynamic_poll_interval_s = float(self.get_parameter('dynamic_poll_interval_s').value)

        self.ultrasonic_echo_timeout_s = float(self.get_parameter('ultrasonic_echo_timeout_s').value)

        self.ultrasonic_sample_count = int(self.get_parameter('ultrasonic_sample_count').value)
        self.ultrasonic_sample_gap_s = float(self.get_parameter('ultrasonic_sample_gap_s').value)
        self.ultrasonic_min_distance_m = float(
            self.get_parameter('ultrasonic_min_distance_m').value
        )
        self.ultrasonic_max_distance_m = float(
            self.get_parameter('ultrasonic_max_distance_m').value
        )
        self.ultrasonic_temperature_c = float(
            self.get_parameter('ultrasonic_temperature_c').value
        )

        self._engage_profiles = {
            'mild': {'engage_us': 1000, 'engage_time_s': 1},
            'medium': {'engage_us': 1200, 'engage_time_s': 1.40},
            'strong': {'engage_us': 1300, 'engage_time_s': 1.52},
        }
        if self.engage_profile not in self._engage_profiles:
            self.get_logger().warn(
                f"Unknown engage_profile '{self.engage_profile}', falling back to 'medium'"
            )
            self.engage_profile = 'medium'

        self.done_pub = self.create_publisher(Bool, '/shoot_done', 10)
        self.create_subscription(String, '/shoot_type', self.trigger_callback, 10)

        self._lock = threading.Lock()
        self._busy = False
        self._pi = None
        self._pigpio_ready = False
        self._global_shot_count = 0

        # Ultrasonic callback state
        self._echo_cb = None
        self._echo_event = threading.Event()
        self._echo_start_tick = None
        self._echo_end_tick = None
        self._measure_lock = threading.Lock()

        if self.enable_hardware:
            self._init_pigpio()
        else:
            self.get_logger().warn('Shooter hardware disabled. Running in simulated mode.')

    def _init_pigpio(self):
        try:
            import pigpio  # pylint: disable=import-outside-toplevel

            self._pi = pigpio.pi(self.pigpiod_host, self.pigpiod_port)
            if not self._pi.connected:
                raise RuntimeError(
                    f'Could not connect to pigpiod at {self.pigpiod_host}:{self.pigpiod_port}'
                )

            self._pi.set_mode(self.gate_pin, pigpio.OUTPUT)
            self._pi.set_mode(self.rack_pin, pigpio.OUTPUT)
            self._pi.set_mode(self.ultrasonic_trigger_pin, pigpio.OUTPUT)
            self._pi.set_mode(self.ultrasonic_echo_pin, pigpio.INPUT)

            self._pi.write(self.ultrasonic_trigger_pin, 0)
            self._pi.set_servo_pulsewidth(self.gate_pin, self.gate_close_us)
            self._pi.set_servo_pulsewidth(self.rack_pin, 0)

            self._echo_cb = self._pi.callback(
                self.ultrasonic_echo_pin,
                pigpio.EITHER_EDGE,
                self._echo_callback
            )

            self._pigpio_ready = True
            self.get_logger().info('Shooter pigpio initialized.')
        except Exception as exc:
            self.enable_hardware = False
            self._pigpio_ready = False
            self.get_logger().error(
                f'Failed to initialize pigpio, falling back to simulated mode: {exc}'
            )

    def _echo_callback(self, gpio, level, tick):
        _ = gpio
        if level == 1:
            self._echo_start_tick = tick
            self._echo_end_tick = None
            self._echo_event.clear()
        elif level == 0 and self._echo_start_tick is not None:
            self._echo_end_tick = tick
            self._echo_event.set()

    def trigger_callback(self, msg: String):
        shoot_type = (msg.data or 'auto').strip().lower()
        if shoot_type not in ('static', 'dynamic', 'bonus', 'auto'):
            shoot_type = 'auto'

        self.get_logger().info(f"Received /shoot_type={shoot_type}, starting shooter cycle")

        with self._lock:
            if self._busy:
                self.get_logger().warn('Shooter busy; ignoring trigger')
                return
            self._busy = True

        threading.Thread(target=self._run_delivery, args=(shoot_type,), daemon=True).start()

    def _run_delivery(self, shoot_type: str):
        success = True

        try:
            if self.enable_hardware and self._pigpio_ready:
                if shoot_type == 'static':
                    self._static_delivery()
                elif shoot_type == 'dynamic':
                    self._dynamic_delivery()
                elif shoot_type == 'bonus':
                    self._bonus_delivery()
                else:
                    self._static_delivery()
            else:
                # Sim mode keeps deterministic completion behavior for CI/Gazebo.
                time.sleep(self.simulated_shot_delay_sec)
        except Exception as exc:
            self.get_logger().error(f'Shooter cycle failed: {exc}')
            success = False
        finally:
            self.done_pub.publish(Bool(data=success))
            with self._lock:
                self._busy = False

            if success:
                self.get_logger().info(
                    f'Shooter cycle complete (type={shoot_type}), published /shoot_done=True'
                )

    def _static_delivery(self):
        delivery2_delay = 0.1
        delivery3_delay = 7.1

        self._shoot_once_hardware()
        time.sleep(delivery2_delay)

        self._shoot_once_hardware()
        time.sleep(delivery3_delay)

        self._shoot_once_hardware()

    def _dynamic_delivery(self):
        shot_count = 0
        pending_launch = False
        active_cycle_index = 0

        while shot_count < 3:
            distance_m = self._read_ultrasonic_distance_m()

            if distance_m is not None and distance_m <= self.ultrasonic_distance_threshold_m:
                shot_number = shot_count + 1
                if not pending_launch:
                    active_cycle_index = self._global_shot_count
                    self.get_logger().info(
                        f'Dynamic pass 1 (load) for shot {shot_number}/3 at {distance_m:.3f} m'
                    )
                    self._dynamic_load_pass(active_cycle_index)
                    pending_launch = True
                else:
                    self.get_logger().info(
                        f'Dynamic pass 2 (launch) for shot {shot_number}/3 at {distance_m:.3f} m'
                    )
                    self._dynamic_launch_pass(active_cycle_index)
                    shot_count += 1
                    pending_launch = False
                continue

            time.sleep(self.dynamic_poll_interval_s)

    def _bonus_delivery(self):
        delivery_delay = 1.0

        for _ in range(3):
            self._shoot_once_hardware()
            time.sleep(delivery_delay)

    def _shoot_once_hardware(self):
        cycle_index = self._global_shot_count

        engage_thread = threading.Thread(target=self._engage_rack, args=(cycle_index,))
        offset = self.engage_to_gate_open_offset_s
        if offset >= 0.0:
            engage_thread.start()
            if offset > 0.0:
                time.sleep(offset)
            self._open_gate()
        else:
            self._open_gate()
            time.sleep(abs(offset))
            engage_thread.start()

        time.sleep(self.ball_drop_s)
        self._close_gate()
        # Keep gate timing independent from rack engage/hold duration.
        engage_thread.join()
        time.sleep(self.close_to_release_s)

        self._disengage_rack(cycle_index)
        self._global_shot_count += 1

    def _dynamic_load_pass(self, cycle_index: int):
        # Pass 1 mirrors the static timing profile up to (and including) gate close,
        # but does not release the rack yet.
        engage_thread = threading.Thread(target=self._engage_rack, args=(cycle_index,))
        offset = self.engage_to_gate_open_offset_s

        if offset >= 0.0:
            engage_thread.start()
            if offset > 0.0:
                time.sleep(offset)
            self._open_gate()
        else:
            self._open_gate()
            time.sleep(abs(offset))
            engage_thread.start()

        time.sleep(self.ball_drop_s)
        self._close_gate()
        engage_thread.join()
        # Rack remains loaded; launch happens on pass 2.

    def _dynamic_launch_pass(self, cycle_index: int):
        # Pass 2 uses the same release timing as static but no extra gate dwell.
        time.sleep(self.close_to_release_s)
        self._disengage_rack(cycle_index)
        self._global_shot_count += 1

    def _get_engage_time_for_cycle(self, cycle_count: int) -> float:
        profile = self._engage_profiles.get(self.engage_profile, self._engage_profiles['mild'])
        _ = cycle_count
        return profile['engage_us'], profile['engage_time_s']

    def _get_disengage_pause_for_cycle(self, cycle_count: int) -> float:
        base = self.rack_cycle_pause_s
        cycle_count = max(0, int(cycle_count))

        if cycle_count == 0:
            trimmed = base
        elif cycle_count <= 2:
            trimmed = base + self.disengage_trim_per_extra_cycle_s
        else:
            trimmed = base + self.disengage_trim_per_extra_cycle_high_s
        return max(0.05, trimmed)

    def _engage_rack(self, cycle_count: int):
        engage_us, engage_time = self._get_engage_time_for_cycle(cycle_count)
        # Continuous servo pullback command.
        self._pi.set_servo_pulsewidth(self.rack_pin, engage_us)
        time.sleep(engage_time)
        self._pi.set_servo_pulsewidth(self.rack_pin, 1500)
        time.sleep(self.rack_hold_duration_s)

    def _disengage_rack(self, cycle_count: int):
        pause_s = self._get_disengage_pause_for_cycle(cycle_count)
        # Continuous servo release command.
        self._pi.set_servo_pulsewidth(self.rack_pin, 1000)
        time.sleep(pause_s)
        self._pi.set_servo_pulsewidth(self.rack_pin, 1500)

    def _open_gate(self):
        self._pi.set_servo_pulsewidth(self.gate_pin, self.gate_open_us)
        time.sleep(self.gate_settle_s)

    def _close_gate(self):
        self._pi.set_servo_pulsewidth(self.gate_pin, self.gate_close_us)
        time.sleep(self.gate_settle_s)

    def _speed_of_sound_m_s(self) -> float:
        return 331.3 + (0.606 * self.ultrasonic_temperature_c)

    def _read_one_ultrasonic_sample_m(self):
        if not (self.enable_hardware and self._pigpio_ready):
            return self.ultrasonic_simulated_distance_m

        import pigpio  # pylint: disable=import-outside-toplevel

        with self._measure_lock:
            self._echo_start_tick = None
            self._echo_end_tick = None
            self._echo_event.clear()

            self._pi.write(self.ultrasonic_trigger_pin, 0)
            time.sleep(0.000002)

            self._pi.gpio_trigger(self.ultrasonic_trigger_pin, 10, 1)

            got_echo = self._echo_event.wait(timeout=self.ultrasonic_echo_timeout_s)
            if not got_echo or self._echo_start_tick is None or self._echo_end_tick is None:
                return None

            pulse_width_us = pigpio.tickDiff(self._echo_start_tick, self._echo_end_tick)
            duration_s = pulse_width_us / 1_000_000.0
            distance_m = (duration_s * self._speed_of_sound_m_s()) / 2.0

            if not (self.ultrasonic_min_distance_m <= distance_m <= self.ultrasonic_max_distance_m):
                return None

            return distance_m

    def _read_ultrasonic_distance_m(self):
        if not (self.enable_hardware and self._pigpio_ready):
            return self.ultrasonic_simulated_distance_m

        samples = []

        for _ in range(max(1, self.ultrasonic_sample_count)):
            value = self._read_one_ultrasonic_sample_m()
            if value is not None:
                samples.append(value)
            time.sleep(self.ultrasonic_sample_gap_s)

        if not samples:
            return None

        samples.sort()
        n = len(samples)
        if n % 2 == 1:
            median = samples[n // 2]
        else:
            median = 0.5 * (samples[n // 2 - 1] + samples[n // 2])

        return median

    def destroy_node(self):
        if self._echo_cb is not None:
            try:
                self._echo_cb.cancel()
            except Exception:
                pass

        if self._pi is not None:
            try:
                self._pi.set_servo_pulsewidth(self.gate_pin, 0)
                self._pi.set_servo_pulsewidth(self.rack_pin, 0)
                self._pi.write(self.ultrasonic_trigger_pin, 0)
                self._pi.stop()
            except Exception:
                pass

        super().destroy_node()


def main(args=None):
    rclpy.init(args=args)
    node = ShooterController()
    try:
        rclpy.spin(node)
    except KeyboardInterrupt:
        pass
    finally:
        node.destroy_node()
        try:
            rclpy.shutdown()
        except Exception:
            pass


if __name__ == '__main__':
    main()

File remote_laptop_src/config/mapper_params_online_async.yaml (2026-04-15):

slam_toolbox:
  ros__parameters:
    solver_plugin: solver_plugins::CeresSolver
    ceres_linear_solver: SPARSE_NORMAL_CHOLESKY
    ceres_preconditioner: SCHUR_JACOBI
    ceres_trust_strategy: LEVENBERG_MARQUARDT
    ceres_dogleg_type: TRADITIONAL_DOGLEG
    ceres_loss_function: None

    odom_frame: odom
    map_frame: map
    base_frame: base_footprint
    scan_topic: /scan
    use_map_saver: true
    mode: mapping

    debug_logging: false
    throttle_scans: 2
    transform_publish_period: 0.02
    map_update_interval: 1.0
    resolution: 0.05
    min_laser_range: 0.12
    max_laser_range: 3.5
    minimum_time_interval: 0.3
    transform_timeout: 0.8
    tf_buffer_duration: 120.0
    stack_size_to_use: 40000000
    enable_interactive_mode: true

    use_scan_matching: true
    use_scan_barycenter: true
    minimum_travel_distance: 0.2
    minimum_travel_heading: 0.2
    scan_buffer_size: 50
    scan_buffer_maximum_scan_distance: 3.5
    link_match_minimum_response_fine: 0.1
    link_scan_maximum_distance: 1.5

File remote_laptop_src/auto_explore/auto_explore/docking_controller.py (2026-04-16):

#!/usr/bin/env python3

import math
import rclpy
from rclpy.node import Node
from geometry_msgs.msg import Twist
from tf2_msgs.msg import TFMessage
from nav_msgs.msg import Odometry
import numpy as np
from sensor_msgs.msg import LaserScan
from rclpy.qos import qos_profile_sensor_data
from std_msgs.msg import String
from std_msgs.msg import Bool



class DockingController(Node):
    def __init__(self):
        super().__init__('docking_controller')

        self.cmd_pub = self.create_publisher(Twist, '/cmd_vel_docking', 10)
        self.status_pub = self.create_publisher(Bool, '/dock_done', 10)
        self.tf_sub = self.create_subscription(TFMessage, '/tf', self.tf_callback, 10)
        self.odom_sub = self.create_subscription(Odometry, '/odom', self.odom_callback, 10)
        self.cmd_state = self.create_subscription(String, '/states', self.state_callback, 10)
        self.subscription = self.create_subscription(
            LaserScan,
            'scan',
            self.scan_callback,
            qos_profile_sensor_data
        )

        # Latest marker data
        self.marker_visible = False
        self.last_seen_time = self.get_clock().now()
        self.timeout_sec = 2

        # --- Added: long marker-loss watchdog ---
        # This is separate from timeout_sec above.
        # timeout_sec is your short "live visibility freshness" timeout.
        # marker_invisible_timeout_sec is the new requested "if marker stays invisible
        # for 30 seconds continuously during docking, fail docking" timeout.
        self.marker_invisible_since = None
        self.marker_invisible_timeout_sec = 30.0
        
        self.latest_tx = None
        self.latest_tz = None
        self.latest_rx = None
        self.latest_ry = None
        self.latest_rz = None
        self.latest_rw = None

        #Bot state from FSM
        self.bot_state = "EXPLORE"
        # Current odom pose
        self.curr_x = 0.0
        self.curr_y = 0.0
        self.curr_yaw = 0.0
        self.odom_ready = False

        # Motion tuning
        self.forward_speed = 0.08
        self.turn_kp = 1.8
        self.max_ang_speed = 0.25
        self.turn_tolerance = math.radians(2.0)
        self.dist_tolerance = 0.01

        # Thresholds
        self.tx_align_tolerance = 0.01     # “face marker exactly”
        self.mid_tz_threshold = 0.30       # first straight approach limit
        self.final_tz_threshold = 0.10     # final docking stop
        self.theta_min_for_manoeuvre = math.radians(2.0)
        self.tx_final_align_tolerance = 0.05

        # State machine
        self.state = "IDLE"

        # --- Added: per-state watchdog ---
        # Track when the current state was entered.
        # If we remain in one active docking state for too long (45 sec),
        # docking will auto-fail and move to ABORT -> IDLE.
        self.state_enter_time = self.get_clock().now()
        self.state_timeout_sec = 45.0

        # Stored motion targets
        self.turn_target_yaw = 0.0
        self.theta = 0.0
        self.side_drive_distance = 0.0
        self.side_turn_direction = 0   # +1 or -1

        # Drive start pose
        self.drive_start_x = 0.0
        self.drive_start_y = 0.0

        #avoidance
        self.robot_r = 0.2
        self.scan_data = None
        self.scan = None
        self.special_search_prev_yaw = 0.0
        self.special_search_accum_yaw = 0.0
        self.special_search_started = False

        self.timer = self.create_timer(0.05, self.timer_callback)

        self.get_logger().info("MoveOnAruco node started")

    def tf_callback(self, msg):
        for transform in msg.transforms:
            if transform.child_frame_id.startswith('aruco_marker_'):
                self.last_seen_time = self.get_clock().now()
                self.marker_visible = True

                # --- Added: reset long invisibility timer when marker is seen again ---
                self.marker_invisible_since = None

                self.latest_tx = transform.transform.translation.x
                self.latest_tz = transform.transform.translation.z
                self.latest_rx = transform.transform.rotation.x
                self.latest_ry = transform.transform.rotation.y
                self.latest_rz = transform.transform.rotation.z
                self.latest_rw = transform.transform.rotation.w
                return

    def state_callback(self, msg):
        self.bot_state = msg.data


    def scan_callback(self,msg):
        self.scan_data = msg
        self.scan = msg.ranges
        self.get_logger().info(f"Front LIDAR reading: {self.get_front_lidar(msg):.3f} m")

    def get_front_lidar(self,msg):
        num_readings = len(msg.ranges)
        window = 5 
        front_indices = list(range(0, window)) + list(range(num_readings - window, num_readings))
        
        # Filter for valid readings within the LIDAR range limits
        valid_ranges = [msg.ranges[i] for i in front_indices 
            if i < num_readings and msg.range_min < msg.ranges[i] < msg.range_max]

        if not valid_ranges:
            return

        return sum(valid_ranges) / len(valid_ranges)


    def localControl(self, scan):
        v = None
        w = None

        if scan is None or len(scan) == 0:
            return v, w

        s = np.array(scan, dtype=float)
        s = np.nan_to_num(s, nan=10.0, posinf=10.0, neginf=0.0)
        n = len(s)

        # front-left: first 1/6 of scan
        left_end = max(1, n // 6)
        for i in range(0, left_end):
            if s[i] < self.robot_r:
                return 0.2, -math.pi / 4

        # front-right: last 1/6 of scan
        right_start = max(0, n - n // 6)
        for i in range(right_start, n):
            if s[i] < self.robot_r:
                return 0.2, math.pi / 4

        return v, w

    def odom_callback(self, msg):
        self.curr_x = msg.pose.pose.position.x
        self.curr_y = msg.pose.pose.position.y

        q = msg.pose.pose.orientation
        self.curr_yaw = self.euler_from_quaternion(q.x, q.y, q.z, q.w)
        self.odom_ready = True

    def euler_from_quaternion(self, x, y, z, w):
        t0 = +2.0 * (w * x + y * z)
        t1 = +1.0 - 2.0 * (x * x + y * y)
        _roll_x = math.atan2(t0, t1)

        t2 = +2.0 * (w * y - z * x)
        t2 = max(min(t2, 1.0), -1.0)
        _pitch_y = math.asin(t2)

        t3 = +2.0 * (w * z + x * y)
        t4 = +1.0 - 2.0 * (y * y + z * z)
        yaw_z = math.atan2(t3, t4)

        return yaw_z

    def quat_to_rotmat(self, qx, qy, qz, qw):
        return np.array([
            [1 - 2*(qy*qy + qz*qz),     2*(qx*qy - qz*qw),     2*(qx*qz + qy*qw)],
            [    2*(qx*qy + qz*qw), 1 - 2*(qx*qx + qz*qz),     2*(qy*qz - qx*qw)],
            [    2*(qx*qz - qy*qw),     2*(qy*qz + qx*qw), 1 - 2*(qx*qx + qy*qy)]
        ])
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

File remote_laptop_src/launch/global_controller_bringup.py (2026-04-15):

#!/usr/bin/env python3

from launch import LaunchDescription
from launch.actions import DeclareLaunchArgument
from launch.substitutions import LaunchConfiguration, PythonExpression
from launch_ros.actions import Node
from ament_index_python.packages import get_package_share_directory
from launch.conditions import IfCondition
import os


def generate_launch_description():
    auto_explore_share = get_package_share_directory('auto_explore')

    use_sim_time_arg = DeclareLaunchArgument(
        'use_sim_time',
        default_value='true',
        description='Use simulation (Gazebo) time if true'
    )

    nav_params_file_arg = DeclareLaunchArgument(
        'nav_params_file',
        default_value=os.path.join(auto_explore_share, 'config', 'params.yaml'),
        description='Path to navigation parameters YAML file'
    )

    enable_fsm_arg = DeclareLaunchArgument(
        'enable_fsm',
        default_value='true',
        description='Enable mission FSM node'
    )

    enable_navigation_arg = DeclareLaunchArgument(
        'enable_navigation',
        default_value='true',
        description='Enable exploration/navigation controller'
    )

    enable_markers_arg = DeclareLaunchArgument(
        'enable_markers',
        default_value='true',
        description='Enable ArUco marker detection'
    )

    enable_pose_publisher_arg = DeclareLaunchArgument(
        'enable_pose_publisher',
        default_value='true',
        description='Enable pose_publisher marker node'
    )

    enable_docking_arg = DeclareLaunchArgument(
        'enable_docking',
        default_value='true',
        description='Enable docking controller'
    )

    enable_shooter_arg = DeclareLaunchArgument(
        'enable_shooter',
        default_value='true',
        description='Enable shooter controller'
    )

    shooter_enable_hardware_arg = DeclareLaunchArgument(
        'shooter_enable_hardware',
        default_value='false',
        description='Enable physical GPIO actuation for shooter (keep false in Gazebo)'
    )

    shooter_pigpiod_host_arg = DeclareLaunchArgument(
        'shooter_pigpiod_host',
        default_value='localhost',
        description='Hostname or IP address of the Raspberry Pi running pigpiod'
    )

    shooter_pigpiod_port_arg = DeclareLaunchArgument(
        'shooter_pigpiod_port',
        default_value='8888',
        description='Port used by pigpiod on the Raspberry Pi'
    )

    shooter_ultrasonic_trigger_pin_arg = DeclareLaunchArgument(
        'shooter_ultrasonic_trigger_pin',
        default_value='23',
        description='Ultrasonic trigger GPIO pin used by shooter dynamic mode'
    )

    shooter_ultrasonic_echo_pin_arg = DeclareLaunchArgument(
        'shooter_ultrasonic_echo_pin',
        default_value='24',
        description='Ultrasonic echo GPIO pin used by shooter dynamic mode'
    )

    shooter_ultrasonic_distance_threshold_m_arg = DeclareLaunchArgument(
        'shooter_ultrasonic_distance_threshold_m',
        default_value='0.20',
        description='Dynamic-mode shot threshold in meters from ultrasonic sensor'
    )

    shooter_ultrasonic_simulated_distance_m_arg = DeclareLaunchArgument(
        'shooter_ultrasonic_simulated_distance_m',
        default_value='0.15',
        description='Simulated ultrasonic distance in meters when shooter hardware is disabled'
    )

    shooter_engage_profile_arg = DeclareLaunchArgument(
        'shooter_engage_profile',
        default_value='medium',
        description='Rack engage profile for shooter pinion behavior: mild|medium|strong'
    )

    use_sim_time = LaunchConfiguration('use_sim_time')
    nav_params_file = LaunchConfiguration('nav_params_file')
    enable_fsm = LaunchConfiguration('enable_fsm')
    enable_navigation = LaunchConfiguration('enable_navigation')
    enable_markers = LaunchConfiguration('enable_markers')
    enable_pose_publisher = LaunchConfiguration('enable_pose_publisher')
    enable_docking = LaunchConfiguration('enable_docking')
    enable_shooter = LaunchConfiguration('enable_shooter')
    shooter_enable_hardware = LaunchConfiguration('shooter_enable_hardware')
    shooter_pigpiod_host = LaunchConfiguration('shooter_pigpiod_host')
    shooter_pigpiod_port = LaunchConfiguration('shooter_pigpiod_port')
    shooter_ultrasonic_trigger_pin = LaunchConfiguration('shooter_ultrasonic_trigger_pin')
    shooter_ultrasonic_echo_pin = LaunchConfiguration('shooter_ultrasonic_echo_pin')
    shooter_ultrasonic_distance_threshold_m = LaunchConfiguration('shooter_ultrasonic_distance_threshold_m')
    shooter_ultrasonic_simulated_distance_m = LaunchConfiguration('shooter_ultrasonic_simulated_distance_m')
    shooter_engage_profile = LaunchConfiguration('shooter_engage_profile')

    mission_controller_node = Node(
        package='auto_explore',
        executable='mission_controller',
        name='mission_controller',
        output='screen',
        parameters=[
            {'use_sim_time': use_sim_time},
        ],
        condition=IfCondition(enable_fsm)
    )

    exploration_controller_node = Node(
        package='auto_explore',
        executable='exploration_controller',
        name='exploration_controller',
        output='screen',
        parameters=[
            nav_params_file,
            {'use_sim_time': use_sim_time},
        ],
        condition=IfCondition(enable_navigation)
    )
    
    pose_publisher_node = Node(
        package='auto_explore',
        executable='pose_publisher',
        name='pose_publisher',
        output='screen',
        parameters=[
            {'use_sim_time': use_sim_time},
            {'image_topic': '/camera/image_raw'},
            {'camera_info_topic': '/camera/camera_info'},
            {'marker_size_m': 0.053},
            {'dictionary': 'DICT_4X4_250'},
        ],
        condition=IfCondition(
            PythonExpression([
                "'", enable_markers, "' == 'true' and '", enable_pose_publisher, "' == 'true'"
            ])
        )
    )
    
    docking_controller_node = Node(
        package='auto_explore',
        executable='docking_controller',
        name='docking_controller',
        output='screen',
        parameters=[
            {'use_sim_time': use_sim_time},
            {'dock_cycle_timeout_sec': 20.0},
            {'target_marker_id': -1},
        ],
        condition=IfCondition(enable_docking)
    )
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

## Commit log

2026-02-20 turtlebot CAD base assembly
    [530480810.SLDPRT, BIC04_C01_PCB.SLDPRT, Barrel guide.SLDPRT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]
2026-02-26 payload design iteration 25/2/26
    [Barrel guide.SLDPRT, Carousell.SLDPRT, Case.SLDPRT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]
2026-02-28 payload design iteration 28/2/26
    [Bidirectional shoulder.STEP, Camera Moudule 3 v8.obj, Camera Moudule 3 v8.step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]
2026-03-02 Add ROS2 frontier exploration submodule
    - Forked from https://github.com/abdulkadrtr/ROS2-FrontierBaseExplorationForAutonomousRobot
    - Translated all comments and print statements to english
    - Frontier exploration can be tested on gazebo
2026-03-02 Convert submodules to regular directories - added ROS2 and turtlebot3_edic as regular files
    [common_properties.urdf, model-1_4.sdf, model-1_4_.sdf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]
2026-03-02 payload design iteration 2/3/26
    [Cam V2.1 v1.SLDPRT, Cam V2.1 v1.step, Camera Moudule 3 v8.SLDPRT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]
2026-03-05 payload design iteration 5/3/26
    [First Layer.SLDASM, Fourth Layer.SLDASM, Second Layer.SLDASM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]
2026-03-19 fix(package): reorganise for singular package build
    [exploration_controller.py, global_bringup.py, global_controller_bringup.py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]
2026-03-25 feat(payload): finalised version 1 of payload assembly
    [First Layer.SLDASM, Fourth Layer.SLDASM, Second Layer.SLDASM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]
2026-03-31 feat(payload): launcher vs redesign MAJOR
    [First Layer.SLDASM, Fourth Layer.SLDASM, Second Layer.SLDASM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]
2026-03-31 feat(cad): ultimate pipeline test
2026-04-07 feat(shooting): add set_servo_angle method; fix(servo): correct gate opening and closing implementation
    [Payload_Delivery.py]
2026-04-08 fix(fsm): add debug logging to mission_controller state transitions
    - Added info logging on state changes for FSM visibility
    - Added info logging on marker detection for debugging
    - Added info logging on map exploration completion
    - Enables verification of FSM state machine operation during mission tests
    [model.sdf]
2026-04-09 docs: add SLAM optimization configuration guide
    - Add required SLAM Toolbox parameter configuration section
    - Document mapper_params_online_async.yaml optimization updates
    - Highlight critical improvements: faster map updates, LiDAR range tuning
    - Include key parameter changes: map_update_interval, minimum_travel_distance/heading
    - Position guide as mandatory setup step before autonomous exploration
2026-04-11 feat(shooter): tuned shooter params for drift calibration and continuoual shooting
    [Pinion_Rotation.py]
2026-04-11 Servo integrated with pinion which is integrated with aruco detection system
2026-04-12 fix(package): slam & nav tuning params lookup fix
    [exploration_controller.py, global_bringup.py, global_controller_bringup.py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]
2026-04-12 fix(docking): Adding mode switching based on FSM state
    [docking_controller.py]
2026-04-12 fix(docking):Compliance with FSM states
    [docking_controller.py]
2026-04-12 fix(imports): add IFCondition import into global_controller_bringup.py
    [global_controller_bringup.py]
2026-04-12 fix(shooter): shooter node testbed architectural refactor to correct shooting sequence and proper GPIO cleanup
    [Payload_Delivery.py, Pinion_Rotation.py, exploration_controller.py]
2026-04-12 fix(shooter): added offset params for shooter tuning
    [Payload_Delivery.py]
2026-04-13 fix(package): integrated shooter testbed into shooter node in auto_explore package
    [global_controller_bringup.py, shooter_controller.py]
2026-04-13 fix(shooter): shooter node fixes
    [shooter_controller.py]
2026-04-13 fix(fsm): standardise to /shoot_done and remove legacy /launch_done
    [mission_controller.py]
2026-04-13 fix(shooter): tuned shooter params for working static delivery
    [shooter_controller.py]
2026-04-13 fix (payload): launcher incremental redesign for reduced gear slipping, increased launch force & servo gate feeding
    [First Layer.SLDASM, Fourth Layer.SLDASM, Second Layer.SLDASM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]
2026-04-14 fix(shooter): Integrated ultrasonic functionality
    [shooter_controller.py]
2026-04-14 feat(feature): Add Yaw Sweep functionality, bot rotates 360 degs after reaching a new node to search for Aruco code
2026-04-14 fix(FSM): removed /zone topic
    [mission_controller.py]
2026-04-14 feat(state): Bot moves back after launching sequence to prevent collision
    [exploration_controller.py, mission_controller.py]
2026-04-14 fix(FSM): launch state hold for shooter node to run
    [mission_controller.py, shooter_controller.py]
2026-04-14 fix(Docking): Change Initial approach distance
    [docking_controller.py]
2026-04-15 fix(package): package cleanup and SLAM buffer for tf message drops
    [docking_controller.py, global_bringup.py, global_controller_bringup.py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]
2026-04-15 Remove yaw rotation sweep from exploration controller
    - Removed sweep_mode, sweep_start_time, and sweep_duration variables
    - Eliminated 3-second yaw sweep pause at waypoints
    - Bot now transitions immediately to next waypoint
    - Improves navigation efficiency through tight maze openings
2026-04-15 feat(exploration): remove yaw rotation sweep at waypoints
2026-04-15 fix(docking): Created abort characteristics to prevent stuck error
    [docking_controller.py]
2026-04-15 fix(shooter): finalised fine tuned shooting params, 9/9 successful x2 runs
    [pose_publisher.py, shooter_controller.py]
2026-04-17 fix(shooter): revert to working shooter logic and repo reorganisation
    [common_properties.urdf, model-1_4.sdf, model-1_4_.sdf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]
2026-04-18 docs: complete interface control and subsystem documentation
    - Add comprehensive ROS topic specifications (16 topics) with message types
    - Document launch arguments across 3 launchers with defaults and descriptions
    - Add timing and rates specifications (delays, loop rates, publishing frequencies)
    - Include 8 error scenarios with fallback behavior and recovery procedures
    - Add interface change rules for future maintenance
    - Complete navigation and FSM subsystem design documentation
    - Add configuration management guide with parameter file references
    - Include 10 troubleshooting issues with solutions
    - Add FSM state flow with 4 states and transition triggers
    - Ensure zero overlap between docs w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
2026-04-18 feat(payload): iterative design of payload v2 based on testing results
    [Barrel guide.SLDPRT, Bidirectional shoulder.STEP, Cam V2.1 v1.SLDPRT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]
2026-04-18 fix(payload): CAD files restructuring
    [Bidirectional shoulder.STEP, Cam V2.1 v1.SLDPRT, Cam V2.1 v1.step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]
2026-04-19 docs(high-level-design): add full system architecture and data flow
2026-04-19 docs: Add comprehensive navigation flowcharts and control loop diagrams
    - Add detailed navigation system flowchart showing 10 Hz control loop
    - Add frontier detection and goal selection flowchart
    - Add sensor input integration diagram
    - Document path planning algorithm with collision verification
    - Include mermaid diagrams for visual understanding of navigation flow
2026-04-19 Revise electrical subsystem documentation structure
    Updated the electrical subsystem documentation to include problem description, design requirements, power budget, and detailed integration of components like servos and sensors.
2026-04-19 fix: correct Mermaid diagram parsing in navigation flowchart
    - Replace HTML entities and mathematical operators in decision node labels
    - Navigation System Flowchart now renders correctly on GitHub
    - Simplified decision node label from mathematical notation to plain text
    - Maintains semantic clarity: 'Distance within target_error tolerance'
2026-04-19 Enhance electrical subsystem documentation with diagrams
    Added diagrams and descriptions for electrical subsystem design and wiring.
